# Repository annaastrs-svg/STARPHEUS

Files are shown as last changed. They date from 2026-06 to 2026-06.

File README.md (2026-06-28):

STARPHEUS BOT
----
good pic boro

giño
starpheis

https://annaastrs-svg.github.io/STARPHEUS-PAG/
Take a look to the web page !

[also my build journal :P](JOURNAL.md)

Orpheus Bot It's a robot inspired by the Hack Club mascot (Orpheus).
Starpheus is a Wall-E type robot.
You can control it with a LogiTECH controller (you control its neck with an MG996R servo motor and the TT motors). 
It has 3 OLEDs that make up its eyes and mouth, simulates emotions with basic state machines (scared, happy, sleepy, neutral),
and uses an HC ultrasonic sensor to avoid collisions.
NOTE: this is a rlly full demo jsjjs 

Design
-------
The complete BOT is 31 cm tall, and 31 cm long counting the arms, its designed to look cool (idk if it is,for me it is), i wanted it to be like a Walle-E type.

Captura de pantalla 2026-06-25 231214
The design was made so that our little Starpheus isn't heavy and has good mobility.

It has details to be able to put our components and hollow parts so that the chassis isn't heavy and has more mobility, as I already mentioned.

details:

holes for 3 OLED screens (2x 0.96 & 0.91 )
a reset button at the back
the ESP32-S3 connector at the back
the ultrasonic sensor in the front
and spots to attach the motors.

I'm an amateur, this is my biggest solo project so far, and I like to challenge myself.
Honestly, I struggled a lot with this project. I changed everything from one moment to the next thousands of times. It was going to have computer vision and an infrared sensor so you could pet it, it was going to be semi-autonomous, but it was very ambitious. This is the beginning of Starpheus; in the future, I’ll improve it and all these ideas will be more than just ideas. 

dormido muerto
back

PCB
---
esquema

esq

Captura de pantalla 2026-06-24 214031

CAD
---
Captura de pantalla 2026-06-25 231259
Captura de pantalla 2026-06-25 225029
Captura de pantalla 2026-06-25 231134

I made this EXCEL with all the connections :B

Videos
---
sorry about the quality and my room mess...

https://github.com/user-attachments/assets/39a8d48d-7ff0-484d-94e4-6cae62331124

https://github.com/user-attachments/assets/a8ff2db2-2984-4ae0-9904-147b8f435752

BOM 
--
| Component | Description | Unit | Cost | Distibutor | Link |
|---|---|---|---|---|---|
| ESP32-S3 | Micro Controler, send code to components | 1 | $34.91  | AlliExpress | https://es.aliexpress.com/item/1005009212121307.html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  |
| DRV8833 | H bridge for motors and control PWM | 1 | $2.50 | AlliExpress | https://es.aliexpress.com/item/1005006151344347.html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 |
| OLED.96 | Display, shows data (orpheus eyes) | 2 | $4.49 | Mercado Libre | https://articulo.mercadolibre.com.mx/MLM-705156753-display-pantalla-oled-128x64-096-para-arduino-_JM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 |
| OLED.91 | Display, shows data (orpheus mouth) | 1 | $1.31 | MercadoLibre |https://www.mercadolibre.com.mx/pantalla-oled-azul-128x32-i2c-091/p/MLM2068167145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  |
| HC-SR04 | Ultra sonic sensor, meausres distance | 1 | $2.96 | Mercado Libre |https://www.mercadolibre.com.mx/sensor-de-distancia-hc-sr04-ultrasonico/p/MLM2039690988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 |
| MG-996R | Servo Motor, orpheus neck | 1 | $7.33 | Amazon | https://www.amazon.com.mx/MG996R-55G-servomotor-Helic%C3%B3ptero-Arduino/dp/B0D7M2Y2BR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 |
| tt engines | Movement or orpheus bot | 2 | $4.00 | AlliExpress | https://es.aliexpress.com/item/1005010779121177.html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 |
| buck converters | For Voltage Protecction of the components  | 3 | $6.76 | Amazon |  https://www.amazon.com.mx/Converter-Aumento-Ajustable-Reguladora-Conector/dp/B09Q8YTQXB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 |
| Resistors 1k | Kit of resistores, It helps with voltages  | 3 | $1.67 | Amazon |https://www.amazon.com.mx/Resistencias-Metal-Film-Resistencia-Electr%C3%B3nicos/dp/B0CT529YD5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 |
| Capacitores 470uf | Kit of Capacitores, It helps with voltages | 3 | $1.21 | AlliExpress | https://es.aliexpress.com/item/1005006079381755.html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 |
| Potobard | Helps With the wiring | 1 | $3.41 | Amazon | https://www.amazon.com.mx/Protoboard-MB-102-Prototipo-soldadura-unidades/dp/B08BCLRLTQ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 |
| Wires Dupont | Kit, Conects the components | 1 | $1.79 | Amazon | https://www.amazon.com.mx/Cables-Pruebas-Opcionales-Surtido-Multicolor/dp/B0DKD315BQ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 |
| Push Botton | I added for a RST button of ESP32 () | 1 | $3.35 | Ebay | https://www.ebay.com/itm/376667835321?itemid=376667835321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 |

There are a lot of components, it's a bit tedious but worth it. I will implement an ESP32 Cam in the future and they cost 3 bucks because I have a spare one. I recommend buying lots of batteries!!

ASSEMBLY 
---

| Orpheus Connections | | | | | | | | | | | |
|---|---|---|---|---|---|---|---|---|---|---|---|
| Come From | | Goes To | | | | Come From | | Goes To | | Goes To | |
| Component | Pin | Component | Pin | | | Component | Pin | Component | Pin | Component | Pin |
| ESP32 S3 | 9 | OLED 1 | SCK | | | Buck 2 | out + | Capacitor 470uf | Positive +  | MG996R | 5V |
| ESP32 S3 | 8 | OLED 1 | SDA | | | | | Capacitor 470uf | Negative -  | Protoboard 1 | Negative |
| ESP32 S3 | 14 | MG996R | S | | | Buck 2 | out - | Protoboard1 | Negative -  | | |
| ESP32 S3 | 10 | OLED 2 | SDA | | | Buck 2 | in + | Protoboard 2 | Positive +  | | |
| ESP32 S3 | 11 | OLED 2 | SCK | | | Buck 2 | in - | Protoboard1 | Negative -  | | |
| ESP32 S3 | 38 | OLED 3 | SDA | | | | | | | | |
| ESP32 S3 | 39 | OLED 3 | SCK | | | Buck 1 | out + | Capacitor 470uf | Positive +  | DRV8833 | 5V |
| ESP32 S3 | 15 | DRV8833 | IN1 | A | | | | Capacitor 470uf | Negative -  | Protoboard 1 | Negative |
| ESP32 S3 | 16 | DRV8833 | IN2 | A | | Buck 1 | out - | Protoboard 1 | Negative | | |
| ESP32 S3 | 17 | DRV8833 | IN3 | B | | Buck 1 | in + | Protoboard 2 | Positive +  | | |
| ESP32 S3 | 18 | DRV8833 | IN4 | B | | Buck 1 | in- | Protoboard 1 | Negative -  | | |
| ESP32 S3 | 5 | HC-SR04 | TRIG | | | | | | | | |
| ESP32 S3 | 6 | R1 (1kohm) | ECHO | R2 (2kohm) | | BATTERY | OUT + | Protoboard 2 | Positive +  | | |
| MG996R | GND | Protoboard 1 | Negative - | | | BATTERY | OUT - | Protoboard 1 | Negative -  | | |
| OLED 0.96  (1 & 2)  | GND | Protoboard 1 | Negative - | | | | | | | | |
| OLED 0.96  (1 & 2)  | 5V | Protoboard 1 | Positive + | | | | | | | | |
| OLED 0.91 | GND | Protoboard 1 | Negative - | | | | | | | | |
| OLED 0.91 | 5V | Protoboard 1 | Positive + | | | | | | | | |
| HC-SR04 | GND | Protoboard 1 | Negative - | | | | | | | | |
| DRV8833 | GND | Protoboard 1 | Negative - | | | | | | | | |
| DRV8833 | OUT1 | MOTOR A | NO POLARIDAD | | | | | | | | |
| DRV8833 | OUT2 | MOTOR A | NO POLARIDAD | | | | | | | | |
| DRV8833 | OUT3 | MOTOR B | NO POLARIDAD | | | | | | | | |
| DRV8833 | OUT4 | MOTOR B | NO POLARIDAD | | | | | | | | |
| | | | | | | | | | | | |
| | | | | | | | | | | | |
| | | | | | | | | | | | |
| | | | | | | | | | | | |
| | | | | | | | | | | | |
| | | | | | | | | | | | |
| | | | | | | | | | | | |

Wiring Little Tutorial, Moustly Explication
----

To build this, there are several things you need to take into account. 
First, the common GND that I implemented with my trusted protoboard: absolutely all the GNDs go to the negative of the protoboard. In the wiring table I made, it's the negative of protoboard 1.
I have divided my protoboard into two sections: the common GND and the 5V for the ESP, the OLEDs, and the ultrasonic sensor,
The second part is for connecting the battery directly and the IN+ of the buck converters, Why don't they go with the other components and get excluded? That's because if we put them together, we’ll damage the components, and that wouldn’t be good. Make sure everything is connected well because sometimes things get loose on the protoboard.  

It’s very logical; you need to make sure the circuit closes properly so it works, and what killed me the most in this project were the voltages, The recommended battery is 7.4V, but after 2 hours of testing it runs out. You can use 6 AA batteries in series or do what I did,I made a long cable by stripping one I had and adapted it to connect to Starpheus. It's like it has a strap, but it's really useful and functional if you're poor like me and can't be buying batteries every 3 hours.

Use 2 capacitors and 3 resistors, 1 capacitor of 470uF for the out+ of the two buck converters (motor and servomotor) so they don't cause power spikes. The resistors are for the ultrasonic sensor. I put a 1k resistor on the wire going from pin 5 of the ESP32S3 to the breadboard; one leg touches that wire directly and the other goes to another wire that goes to the echo of the HCSR04. On that same pin, I directly put two 1k resistors in series to make 2k, and the other leg goes to GND. This is so that the HCSR04 doesn't make too much noise since it's at 5V along with the OLEDs and the ESP32S3.  

Since we have many components drawing a lot of current, we have to consider the motors. In the math part, you need to know a bit about static friction and kinetic friction. Kinetic friction has to be greater than static friction because generally the coefficient of static friction is always higher than the kinetic one, so the motor force has to be greater than the maximum static friction force.
wires

LICENSE
---
MIT

PS:(sorry for some gramatic errors and bad spelling, enlish is not my best lenguage)
thank you a lot hack club staff and people looking at this <3

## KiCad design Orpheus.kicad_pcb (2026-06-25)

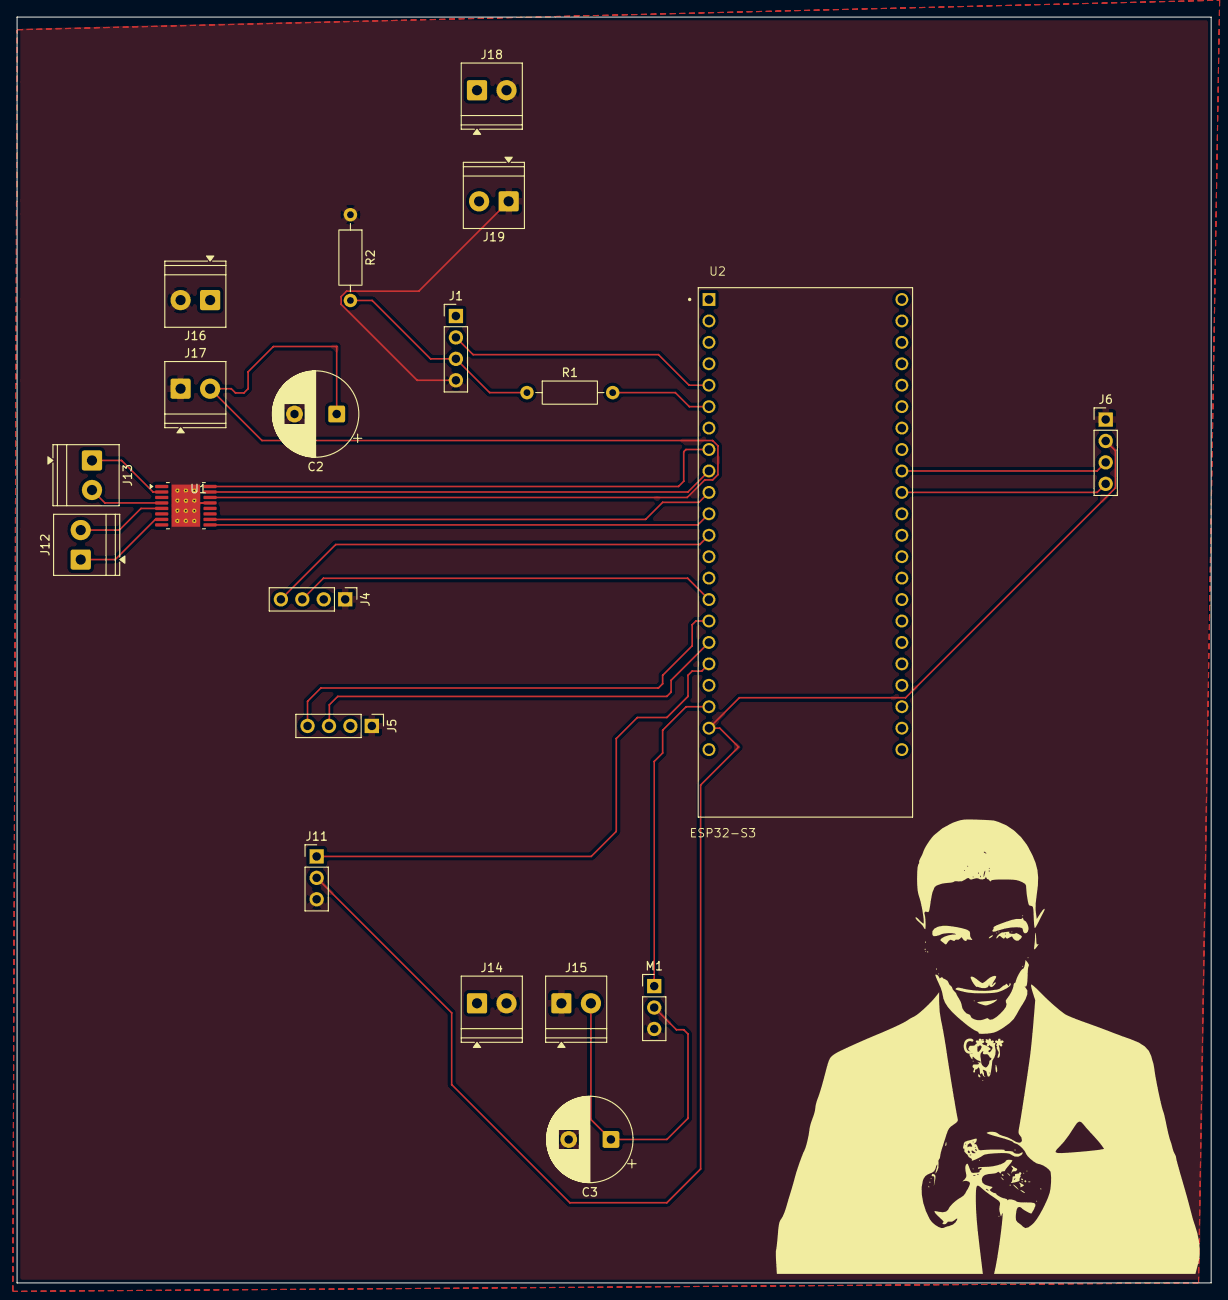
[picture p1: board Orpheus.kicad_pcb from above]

Board: 2 copper layers, 141.5 x 150.0 mm, 20 parts (0 on the bottom side), 21 nets.

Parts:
C2, C3: 470uf; CP_Radial_D10.0mm_P5.00mm
J1: HC-SR04; PinHeader_1x04_P2.54mm_Vertical
J4: OLED 0.91; PinHeader_1x04_P2.54mm_Vertical
J5, J6: OLED 0.96 (2); PinHeader_1x04_P2.54mm_Vertical
J11: IR; PinHeader_1x03_P2.54mm_Vertical
J12: Motor B; TerminalBlock_Phoenix_PT-1,5-2-3.5-H_1x02_P3.50mm_Horizontal
J13: Motor A; TerminalBlock_Phoenix_PT-1,5-2-3.5-H_1x02_P3.50mm_Horizontal
J14, J18: BUCK 2 IN; TerminalBlock_Phoenix_PT-1,5-2-3.5-H_1x02_P3.50mm_Horizontal
J15, J19: BUCK 2 OUT; TerminalBlock_Phoenix_PT-1,5-2-3.5-H_1x02_P3.50mm_Horizontal
J16: BUCK 1 IN; TerminalBlock_Phoenix_PT-1,5-2-3.5-H_1x02_P3.50mm_Horizontal
J17: BUCK 1 OUT; TerminalBlock_Phoenix_PT-1,5-2-3.5-H_1x02_P3.50mm_Horizontal
M1: MG996R; PinHeader_1x03_P2.54mm_Vertical
R1: 2k; R_Axial_DIN0207_L6.3mm_D2.5mm_P10.16mm_Horizontal
R2: 1k; R_Axial_DIN0207_L6.3mm_D2.5mm_P10.16mm_Horizontal
U1: DRV8833PWP; HTSSOP-16-1EP_4.4x5mm_P0.65mm_EP3.4x5mm_Mask2.46x2.31mm_The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
U2: ESP32-S3; XCVR_ESP32-S3-DEVKITC-1U-N8R2

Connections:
+: C2.1, C3.1, J1.1, J4.2, J5.2, J6.2, J11.2, J14.1, J15.2, J16.1, J17.2, J18.1, J19.2, M1.2 (+), U1.14 (VINT), U2.J1_21 (5V0)
-: C2.2, C3.2, J1.4, J4.1, J5.1, J6.1, J11.3, J14.2, J15.1, J16.2, J17.1, J18.2, J19.1, M1.3 (-), R2.1, U1.13 (GND), U1.17 (GND)
ECHO: J1.3, R1.1, R2.2
unnamed: J12.1, U1.7 (BOUT1)
unnamed: J12.2, U1.5 (BOUT2)
unnamed: J13.1, U1.2 (AOUT1)
unnamed: J13.2, U1.4 (AOUT2)
unnamed: M1.1 (PWM), U2.J1_20 (GPIO14)
unnamed: U1.16 (AIN1), U2.J1_8 (GPIO15)
unnamed: U1.15 (AIN2), U2.J1_9 (GPIO16)
unnamed: U1.9 (BIN1), U2.J1_11 (GPIO18)
unnamed: U1.10 (BIN2), U2.J1_10 (GPIO17)
unnamed: R1.2, U2.J1_6 (GPIO6)
S: J11.1, U2.J1_18 (GPIO12)
SCK B: J4.3, U2.J1_15 (GPIO9)
SCK OD: J5.3, U2.J1_17 (GPIO11)
SCK OI: J6.3, U2.J3_9 (MTCK/GPIO39)
SDA B: J4.4, U2.J1_12 (GPIO8)
SDA OD: J5.4, U2.J1_16 (GPIO10)
SDA OI: J6.4, U2.J3_10 (GPIO38)
TRIG: J1.2, U2.J1_5 (GPIO5)

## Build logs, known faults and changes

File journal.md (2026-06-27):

A Walle-Etype companion robot inpired by Orpheus, the Hack Club mascot.
face, emotions, ultrasonic sensing and Logitech control.

STARPHEUS 
----
Anna Strs (annaastrs-svg)

2026-06-01

STARPHEUS JOURNAL !
---

starpheus bot is a robot inpired by orpheus, you can controll it, but he reacts to his enviroment with his face made by 3 OLEDS (1 per eye and 1 for mouth).

total time spent so far: ~70 hrs

THE IDEA
---

i love to build cute things that have its own "life" starpheus is interactive and has mobility. 
I dont remember exactly how or why i thought about orpheus.
The complete plan with starpheus was: computer vision, autonomus, curious and infrared sensors. 

STARPHEUS first sketchs:
---
Captura de pantalla 2026-06-20 233143
Captura de pantalla 2026-06-21 210439

The emotional Face
----

first thing i built was the face, two oleds were the start, one for mouth and other one for eyes, (I changed it cus it was too small)
the first state machine for emotions : neutral, sleepy, angry, heart face.

the challenge of this came after, the oleds share the same I2C adress (0x3C) so they fight if you put thwm on the same bus. i had to separate I2C buses. 

WhatsApp Image 2026-06-19 at 2 52 02 PM

The neck servomotor
----

the mg9963 for the neck gave me SO much touble. It wouldnt move with low current, some thimes he dont even move...
i learned after 2 hours that:
it needs enough current 
it needs a capacitor 470uf or it browns out
loose wires ruin evrything....

The worst decision of my life (ESP32 CAM)
----

the idea of starpheus was to SEE YOU. computer vision was the goal. 
but it nnever worked at any point, because the camera I got was  CLONE, and it didnt work with any library,
I really tryed SO MUCH 😿 
in the end i made a hard decision. drop the camera and ude a ultrasonic sensor to detect presence instead.
the computer vision idea STAYS for future improvement.
Captura de pantalla 2026-06-19 183814
Captura de pantalla 2026-06-19 173344
the camera detected the face position in Y and X nut never send the info to my ESP32S3  

PCB!!
--
I designed a costum PCB in KiCAD, to make conecctions cleaner instead of the mess i have, unfortunetly i dont have the money for buying it...

Captura de pantalla 2026-06-24 195610
esquema
Captura de pantalla 2026-06-24 214031

The body CAD 3D
----
I designed the chassis, a complete bot 31 cm tall and 31 cm long counting the arms. 
it have a lot of details and is thinked for it to dont being heavy, so the movement can be better.
Captura de pantalla 2026-06-25 231259
Captura de pantalla 2026-06-25 231148
Captura de pantalla 2026-06-25 231214

have details so u can put ur ESP32S3
a botton for RST the esp32s3 
the oled holes
ultrasonic hole
and to attach the motors.

Power struggles
----
The power was the thing that killed me the most.
the recommend batterry is 7.4V 2S LiPo but i cant afford it lol
and i learned that 9V battery DONT WORK OUT they give voltage but they dont give enough current
so that makes the motors drown it.

I made my own stripping one, I had and adapted it so Starpheus can run from a wall, its like it has a strap but is really usefull and functional if u are poor just like me.
you can also use a 6AA baterries in series, I tryed but i think i did it wrong cus they started overheating
REMEMBER this is a really worked out demo so eventually ill add a 7.4V battery.

Putting it all together
-----
I made a really complete excel with all the wires you need to make.
Captura de pantalla 2026-06-24 170230
Honestly i struggled a lot with this, my head still hurts thinking about this...

What I learned 
---

I learned a lot with this project. 
sometimes u dont notices evrything has to do with math, the friction maths for the motor are soo cool 
its hard sometimes cus you dont know were to start or ypu are scared of trying and not making it "that good" 
but i guess we all start somewhere, u just need to dont make it with fear 

Future improvements
---
COMPUTER VISION! with a no clone camarra that actually follows ur face with the neck.
a proper battery...
audio and sound expressions 
a more complete control app

Photos i like about starpheus construction}
---

Captura de pantalla 2026-06-26 234659
Controll pag is complete FIREEE 
Captura de pantalla 2026-06-26 234435
i was so happy, looks amazing that starpheus have internet its so cute 
Captura de pantalla 2026-06-25 225412
AJJSSJSJS HE LOOKS SO TIRED HELL NAAA
Captura de pantalla 2026-06-25 225356
I tried making a serie of AA batterys but i lit burn my finger, still hurts...a lot 
Captura de pantalla 2026-06-22 150748
Bro dont event exist but exist for me :octocat:

Captura de pantalla 2026-06-22 215209
AWWWA the start of all... 

PS:Thanks u all for looking at these im rlly greatfull <3

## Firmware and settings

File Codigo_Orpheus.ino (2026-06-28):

/*
 * STARPHEUS CONTROL - V2.0 Emociones y Arcade Drive
 * Control Arcade (Logitech) + Anti-friccion + Sistema de Emociones
 *
 * Trig=5 | Echo=6 | Motores DRV8833: 15, 16, 17, 18
 * Ojo izq: SDA=10 SCL=11 | Ojo der: SDA=38 SCL=39 | Boca: SDA=8 SCL=9
 */

#include <Wire.h>
#include <Adafruit_GFX.h>
#include <Adafruit_SSD1306.h>
#include <U8g2lib.h>
#include <WiFi.h>
#include <WebServer.h>

const char* ssid = "Starpheus_Bot";
const char* password = "123456789";
WebServer server(80);

// ===== Pantallas =====
TwoWire I2Cboca = TwoWire(0);
Adafruit_SSD1306 boca(128, 32, &I2Cboca, -1);
U8G2_SSD1306_128X64_NONAME_F_SW_I2C ojoIzq(U8G2_R0, 11, 10, U8X8_PIN_NONE);
U8G2_SSD1306_128X64_NONAME_F_SW_I2C ojoDer(U8G2_R0, 39, 38, U8X8_PIN_NONE);

// ===== Pines =====
#define IN1 15   // Motor IZQ adelante
#define IN2 16   // Motor IZQ atras
#define IN3 17   // Motor DER adelante
#define IN4 18   // Motor DER atras

#define TRIG_PIN 5
#define ECHO_PIN 6

// ===== Parametros de movimiento =====
const int PWM_FREQ = 5000;
const int PWM_RES = 8;              
const int JALON_PWM = 255;          
const unsigned long JALON_MS = 120; 

// ===== Anti-choque =====
const int DIST_PELIGRO = 12;        
const int DIST_DESPERTAR = 40;

// ===== Estado de control =====
int targetIzq = 0;     
int targetDer = 0;     
unsigned long ultimoComando = 0;
const unsigned long TIMEOUT_CTRL = 600;  

// ===== Variables de Logica =====
bool izqEnMovimiento = false;
bool derEnMovimiento = false;
unsigned long jalonIzqInicio = 0;
unsigned long jalonDerInicio = 0;

long distanciaActual = 999;
unsigned long ultimaMedicion = 0;

// ===== Temporizadores de Emocion =====
unsigned long tiempoQuieto = 0;
unsigned long tiempoRapido = 0;
unsigned long ultimoParpadeo = 0;

// Estados: 0=Idle, 1=Manual, 2=Dormido, 3=Asustado, 4=Euforico
int estadoActual = -1; 

void configMotores() {
  ledcAttach(IN1, PWM_FREQ, PWM_RES);
  ledcAttach(IN2, PWM_FREQ, PWM_RES);
  ledcAttach(IN3, PWM_FREQ, PWM_RES);
  ledcAttach(IN4, PWM_FREQ, PWM_RES);
}

long medirDistancia() {
  digitalWrite(TRIG_PIN, LOW); delayMicroseconds(2);
  digitalWrite(TRIG_PIN, HIGH); delayMicroseconds(10);
  digitalWrite(TRIG_PIN, LOW);
  uint32_t t = micros();
  while (digitalRead(ECHO_PIN) == LOW) { if (micros() - t > 8000) return 999; }
  uint32_t s = micros();
  while (digitalRead(ECHO_PIN) == HIGH) { if (micros() - s > 8000) return 999; }
  long d = (micros() - s) * 0.034 / 2;
  return (d < 2 || d > 300) ? 999 : d;
}

// Control seguro del motor con Jalón
void moverMotor(int potencia, int pinAdel, int pinAtras, bool &enMov, unsigned long &jalonInicio) {
  if (potencia == 0) {
    ledcWrite(pinAdel, 0);
    ledcWrite(pinAtras, 0);
    enMov = false;
    return;
  }

  if (!enMov) { enMov = true; jalonInicio = millis(); }
  
  bool enJalon = (millis() - jalonInicio < JALON_MS);
  int pwm = enJalon ? JALON_PWM : abs(potencia);

  if (potencia > 0) {
    ledcWrite(pinAtras, 0); // Apagar estricto el contrario primero
    ledcWrite(pinAdel, pwm);
  } else {
    ledcWrite(pinAdel, 0); // Apagar estricto el contrario primero
    ledcWrite(pinAtras, pwm);
  }
}

// ===== DIBUJOS DE OJOS =====
void dibujarOjo(U8G2 &o, int tipo) {
  o.clearBuffer(); o.setDrawColor(1);
  if (tipo == 0) { // Normal/Idle
    o.drawDisc(64,32,26); o.setDrawColor(0); o.drawDisc(72,24,9); o.drawDisc(56,40,4);
  } else if (tipo == 1) { // Manual/Atento
    o.drawBox(38,18,52,6); o.drawDisc(64,38,16); o.setDrawColor(0); o.drawDisc(64,38,7);
  } else if (tipo == 2) { // Dormido
    o.drawLine(34, 40, 94, 40); o.drawLine(34, 41, 94, 41);
  } else if (tipo == 3) { // Asustado (Pupila pequeñita)
    o.drawDisc(64, 32, 28); o.setDrawColor(0); o.drawDisc(64, 32, 24); 
    o.setDrawColor(1); o.drawDisc(64, 32, 5);
  } else if (tipo == 4) { // Euforico (Arcos felices ^_^)
    o.drawDisc(64, 40, 26); o.setDrawColor(0); o.drawDisc(64, 48, 26); 
  } else if (tipo == 5) { // Parpadeo
    o.drawBox(34,30,60,5);
  }
  o.sendBuffer();
}

// ===== DIBUJOS DE BOCA =====
void dibujarBoca(int tipo) {
  boca.clearDisplay();
  if (tipo == 0) { // Idle (V pequeña)
    boca.drawLine(54,12,64,22,SSD1306_WHITE); boca.drawLine(64,22,74,12,SSD1306_WHITE);
  } else if (tipo == 1) { // Manual (Linea concentrada)
    boca.fillRect(48,15,32,4,SSD1306_WHITE);
  } else if (tipo == 2) { // Dormido (Zzz)
    boca.setTextSize(2); boca.setTextColor(SSD1306_WHITE);
    boca.setCursor(44, 10); boca.print("Zzz");
  } else if (tipo == 3) { // Asustado (O perfecta)
    boca.drawCircle(64, 16, 12, SSD1306_WHITE);
  } else if (tipo == 4) { // Euforico (Sonrisa grande)
    boca.fillRoundRect(40, 8, 48, 16, 8, SSD1306_WHITE);
  }
  boca.display();
}

// Cambiador de estados
void cambiarCara(int nuevoEstado) {
  if (estadoActual == nuevoEstado) return;
  estadoActual = nuevoEstado;
  dibujarOjo(ojoIzq, nuevoEstado); dibujarOjo(ojoDer, nuevoEstado);
  dibujarBoca(nuevoEstado);
}

// ===== WEB Y CONTROL (ARCADE DRIVE JS) =====
void manejarControl() {
  if (server.hasArg("izq")) targetIzq = constrain(server.arg("izq").toInt(), -255, 255);
  if (server.hasArg("der")) targetDer = constrain(server.arg("der").toInt(), -255, 255);
  ultimoComando = millis();
  server.send(200, "text/plain", "OK");
}

void manejarRaiz() {
  String h = "<!DOCTYPE html><html lang='es'><head><meta charset='UTF-8'>";
  h += "<meta name='viewport' content='width=device-width,initial-scale=1,user-scalable=no'>";
  h += "<title>STARPHEUS</title><style>";
  h += "*{margin:0;padding:0;box-sizing:border-box;-webkit-tap-highlight-color:transparent;}";
  h += "body{background:#05070d;color:#d7e6ff;font-family:monospace;min-height:100vh;overflow:hidden;}";
  h += "h1{text-align:center;color:#2f8fff;padding:20px; font-size:2rem;}";
  h += "button{background:#0c1320;color:#d7e6ff;border:1px solid #26426e;font-size:1.3rem;border-radius:12px;cursor:pointer;}";
  h += "button:active{background:#2f8fff;}";
  h += ".pad{display:flex;flex-direction:column;align-items:center;gap:15px;padding:20px;}";
  h += ".dir{width:120px;height:80px;} .dpad{display:flex;gap:15px;}";
  h += ".stop{width:255px;height:70px;background:#ff4757;color:#fff;}";
  h += ".gp{text-align:center;color:#2f8fff;padding:20px; font-size: 0.8rem;}";
  h += "</style></head><body>";
  h += "<h1>STARPHEUS</h1>";
  h += "<div class='pad'>";
  h += "<button class='dir' ontouchstart='mover(180,180)' ontouchend='mover(0,0)'>Avanzar</button>";
  h += "<div class='dpad'>";
  h += "<button class='dir' ontouchstart='mover(-160,160)' ontouchend='mover(0,0)'>Izquierda</button>";
  h += "<button class='dir' ontouchstart='mover(160,-160)' ontouchend='mover(0,0)'>Derecha</button>";
  h += "</div>";
  h += "<button class='dir' ontouchstart='mover(-160,-160)' ontouchend='mover(0,0)'>Atras</button>";
  h += "<button class='stop' ontouchstart='mover(0,0)'>FRENAR</button>";
  h += "</div><div class='gp' id='gpinfo'>Conecta un mando Logitech</div>";

  h += "<script>";
  h += "let lastSend=0; function enviar(i,d){let now=Date.now();if(now-lastSend<40)return;lastSend=now;fetch('/control?izq='+i+'&der='+d).catch(e=>{});}";
  h += "function mover(i,d){enviar(i,d);} let gpActivo=false;";
  h += "window.addEventListener('gamepadconnected',(e)=>{gpActivo=true;document.getElementById('gpinfo').innerText='Gamepad: '+e.gamepad.id.substring(0,25);bucle();});";
  h += "function bucle(){if(!gpActivo)return;const gp=navigator.getGamepads()[0];if(gp){";
  h += "let y=-gp.axes[1]; let x=gp.axes[0];"; // Arcade Drive Logic
  h += "if(Math.abs(y)<0.15)y=0; if(Math.abs(x)<0.15)x=0;"; // Deadzone
  h += "let li=y+x; let ld=y-x;";
  h += "let mx=Math.max(1, Math.max(Math.abs(li), Math.abs(ld))); li/=mx; ld/=mx;";
  h += "enviar(Math.round(li*255), Math.round(ld*255));";
  h += "}requestAnimationFrame(bucle);}</script></body></html>";
  server.send(200, "text/html", h);
}

void setup() {
  Serial.begin(115200);
  pinMode(38, OUTPUT); digitalWrite(38, LOW); delay(10); pinMode(38, INPUT); // Liberar pin 38
  pinMode(TRIG_PIN, OUTPUT); pinMode(ECHO_PIN, INPUT);
  digitalWrite(TRIG_PIN, LOW);

  configMotores();
  
  I2Cboca.begin(8, 9);
  boca.begin(SSD1306_SWITCHCAPVCC, 0x3C);
  ojoIzq.begin(); ojoDer.begin();

  WiFi.softAP(ssid, password);
  server.on("/", manejarRaiz); server.on("/control", manejarControl);
  server.begin();
  
  cambiarCara(0); // Inicia Idle
  tiempoQuieto = millis();
}

void loop() {
  server.handleClient();

  if (millis() - ultimaMedicion > 60) {
    distanciaActual = medirDistancia();
    ultimaMedicion = millis();
  }

  bool ctrlVivo = (millis() - ultimoComando < TIMEOUT_CTRL);
  int izq = ctrlVivo ? targetIzq : 0;
  int der = ctrlVivo ? targetDer : 0;

  bool peligro = (distanciaActual < DIST_PELIGRO);
  bool moviendo = (izq != 0 || der != 0);
  bool rapido = (abs(izq) >= 200 && abs(der) >= 200);

  // LOGICA ANTI-CHOQUE FRONTAL
  if (peligro && izq > 0 && der > 0) {
    izq = 0; der = 0; 
  }

  // APLICAR MOTORES
  moverMotor(izq, IN1, IN2, izqEnMovimiento, jalonIzqInicio);
  moverMotor(der, IN3, IN4, derEnMovimiento, jalonDerInicio);

  // ===== MAQUINA DE ESTADOS EMOCIONALES =====
  if (moviendo) {
    tiempoQuieto = millis(); // Resetea temporizador de sueño
    if (!rapido) tiempoRapido = millis(); // Solo acumula tiempo si va rapido
  } else {
    tiempoRapido = millis(); // Si se detiene, pierde la euforia
  }

  if (peligro) {
    cambiarCara(3); // Asustado
  } else if (moviendo && (millis() - tiempoRapido > 3000)) {
    cambiarCara(4); // Euforico despues de 3 seg rapido
  } else if (moviendo) {
    cambiarCara(1); // Manual/Atento
  } else {
    // Si no se esta moviendo
    if (millis() - tiempoQuieto > 5000) {
      if (distanciaActual > 0 && distanciaActual < DIST_DESPERTAR) {
        cambiarCara(0); // Alguien paso cerca, despierta a Idle
        tiempoQuieto = millis(); // Resetea el tiempo para que no se vuelva a dormir al instante
      } else {
        cambiarCara(2); // Dormido
      }
    } else {
      cambiarCara(0); // Idle normal
      
      // Parpadeo solo en Idle
      if (estadoActual == 0 && millis() - ultimoParpadeo > 3500 && random(0,100) < 30) {
        dibujarOjo(ojoIzq, 5); dibujarOjo(ojoDer, 5);
        delay(100);
        dibujarOjo(ojoIzq, 0); dibujarOjo(ojoDer, 0);
        ultimoParpadeo = millis();
      }
    }
  }
}

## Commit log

2026-06-25 CAD . gerber files
2026-06-25 CAD PCB
    [Orpheus.kicad_pcb]
2026-06-27 Revise README with updated wiring and assembly details
    Updated the wiring table and BOM with new components and links. Added assembly instructions and wiring tutorial for the project.
